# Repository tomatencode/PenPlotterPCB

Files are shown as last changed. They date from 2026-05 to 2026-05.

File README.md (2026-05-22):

# Pen Plotter Controller Board

Eine selbst entworfene PCB-Steuerplatine für einen DIY Pen Plotter, entwickelt in KiCad. Die Platine steuert zwei Schrittmotoren für die XY-Bewegung, einen Servo für den Stifthub und übernimmt Benutzerführung sowie Energiemanagement vollständig auf einer einzigen Platine.

## Funktionen

- **ESP32** – Haupt-Mikrocontroller (Breakout aufgelötet) für Bewegungssteuerung und Logik
- **2× TMC2209** – Schrittmotortreiber (Breakouts aufgelötet) mit UART-Konfiguration, stealthChop und stallGuard
- **SG90 Servo** – Stift-Auf/Ab-Mechanismus
- **I2C LCD-Display** – Angeschlossen über Steckverbinder
- **Drehgeber** – Manuelle Steuerung und Menünavigation über Steckverbinder
- **Buzzer** – Akustisches Feedback
- **Lüfter** – Transistorgesteuerter Lüfter zur Kühlung der Motortreiber
- **5V Buck Converter** – (Breakout aufgelötet) Erzeugt die interne 5V-Versorgungsschiene aus 24V
- **24V DC-Eingang** – Versorgung über externen Transformator (DC-Hohlbuchse)

## Stromversorgungsarchitektur

| Schiene | Quelle | Verbraucher |
|---|---|---|
| 24 V | Externer Transformator (DC-Buchse) | TMC2209 Motorspannung, Lüfter |
| 5 V | Buck Converter Breakout | ESP32, Servo, Buzzer, LCD |
| 3,3 V | Interner LDO des ESP32 | TMC2209 Logikspannung, Drehgeber |

## Platinenübersicht

### Schaltplan
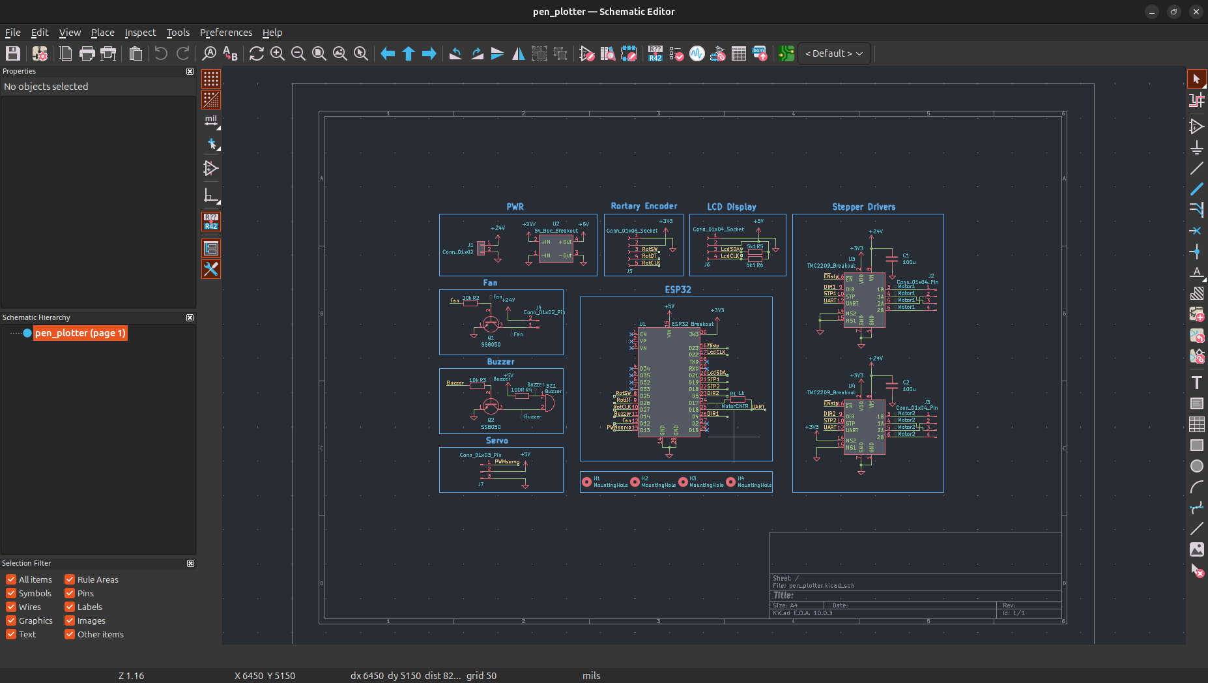
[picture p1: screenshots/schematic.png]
Schaltplan


### PCB-Layout
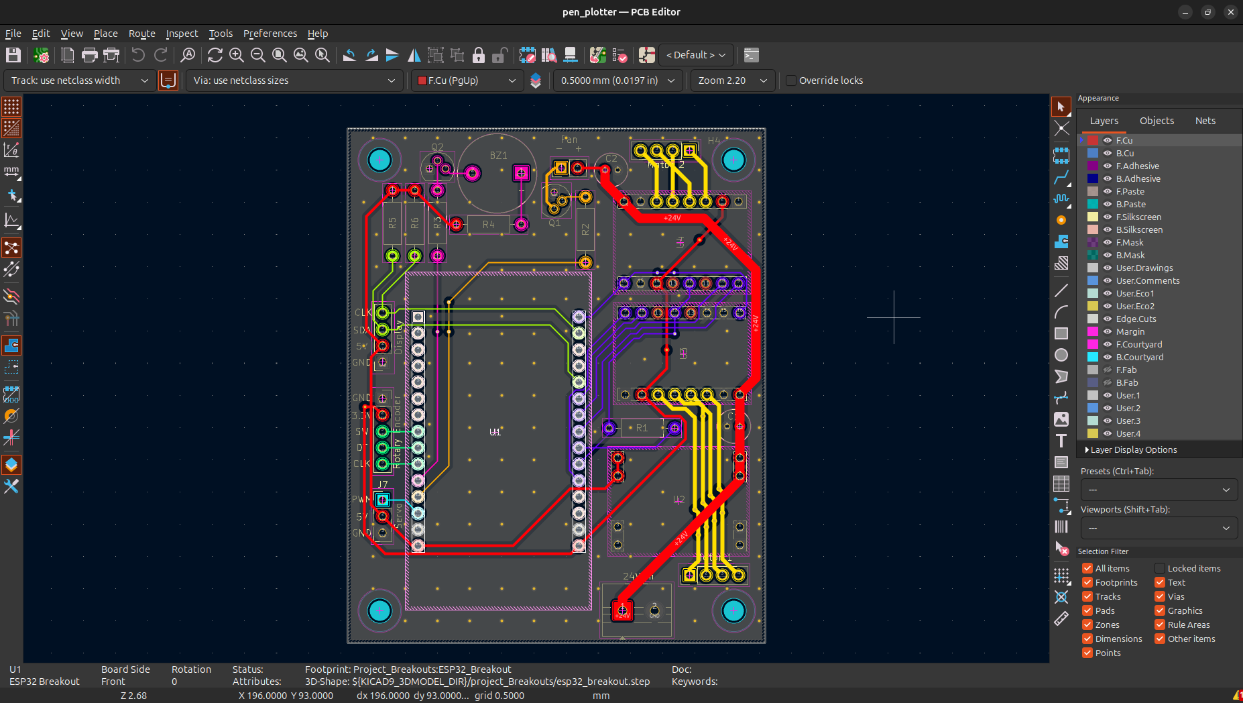
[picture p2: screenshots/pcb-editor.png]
PCB-Layout


### 3D-Ansicht
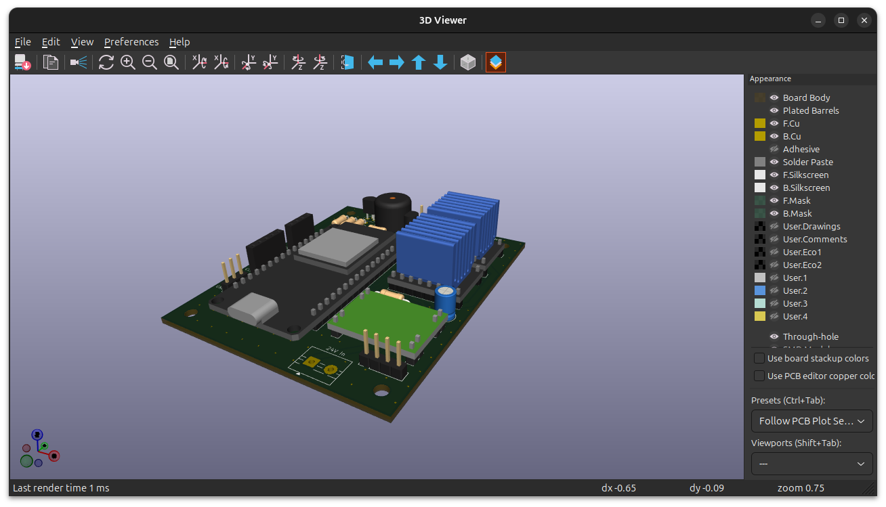
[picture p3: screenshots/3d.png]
3D-Ansicht


## Entwickelt mit

- [KiCad](https://www.kicad.org/) – Schaltplan und PCB-Layout

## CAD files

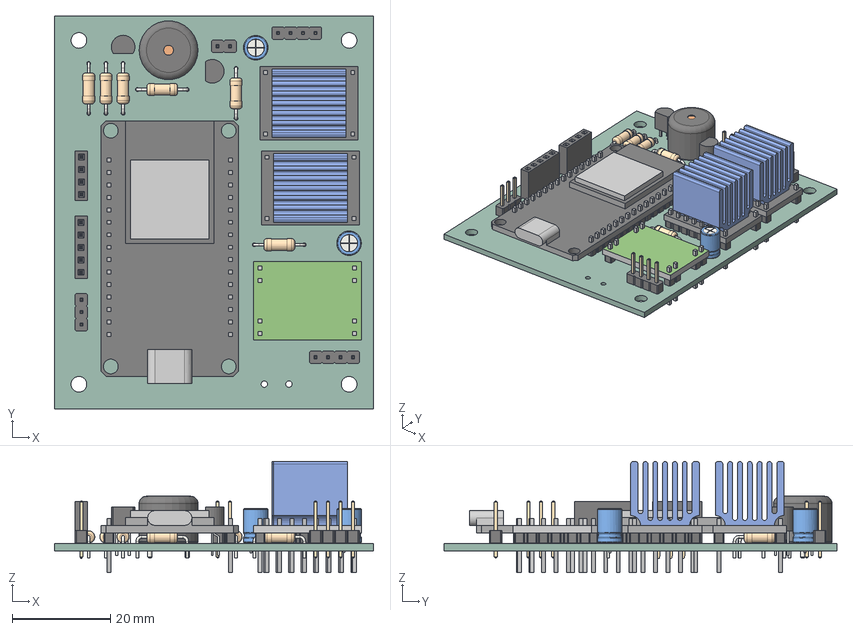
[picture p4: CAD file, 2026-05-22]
pen_plotter.step
65.0 x 80.0 x 22.6 mm
TO-92 x 2
5V_Buc_Breakout
C_Radial_D5.0mm_H7.0mm_P2.00mm x 2
PinHeader_1x03_P2.54mm_Vertical
R_Axial_DIN0207_L6.3mm_D2.5mm_P10.16mm_Horizontal x 6
PinHeader_1x04_P2.54mm_Vertical x 2
TMC2209_Breakout x 2
esp32_breakout
PinHeader_1x02_P2.54mm_Vertical
PinSocket_1x04_P2.54mm_Vertical
Buzzer_12x9.5RM7.6
PinSocket_1x05_P2.54mm_Vertical
pen_plotter_PCB

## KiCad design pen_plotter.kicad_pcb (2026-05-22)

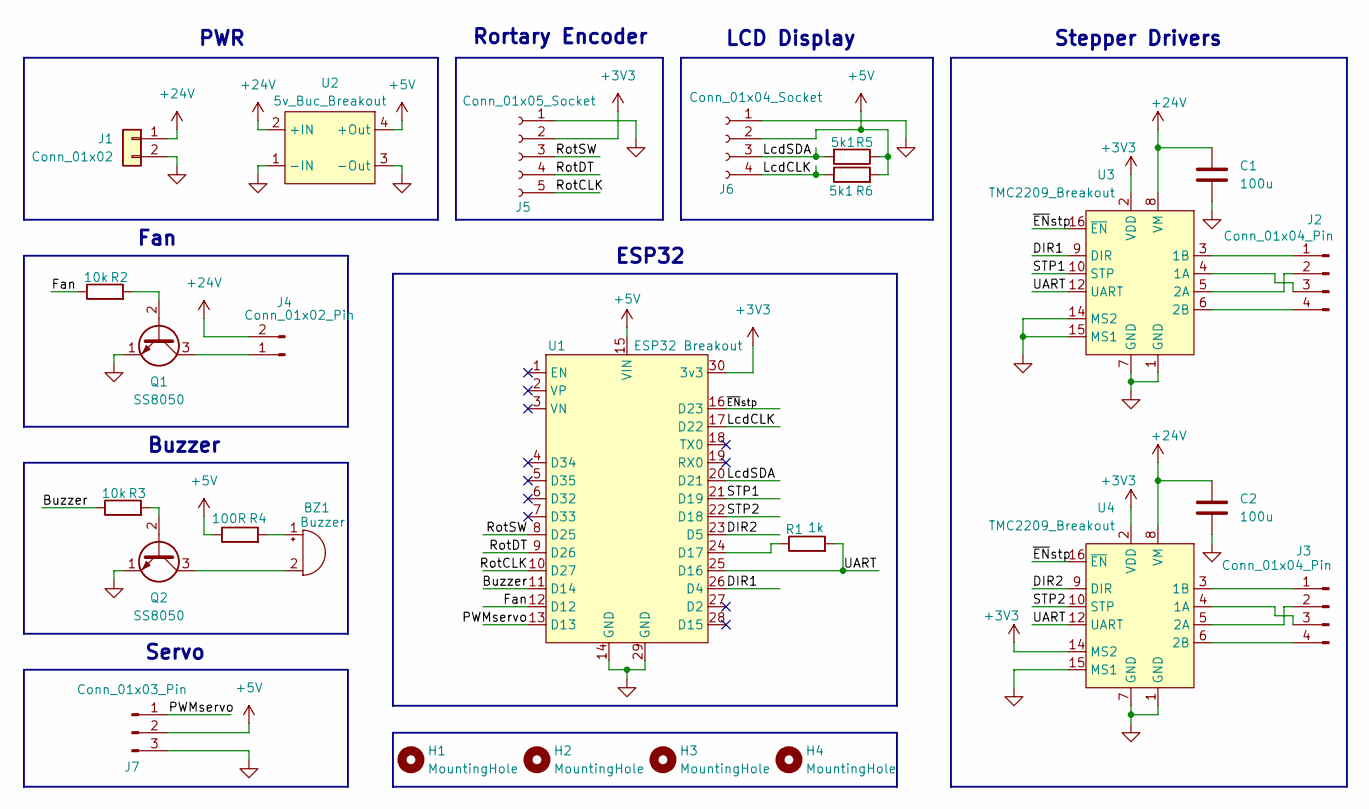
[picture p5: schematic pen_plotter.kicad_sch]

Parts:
BZ1: Buzzer; Buzzer_12x9.5RM7.6
C1, C2: 100u; C_Radial_D5.0mm_H7.0mm_P2.00mm
H1, H2, H3, H4: MountingHole; MountingHole_3.2mm_M3
J1: Conn_01x02; TerminalBlock_MaiXu_MX126-5.0-02P_1x02_P5.00mm
J2, J3: Conn_01x04_Pin; PinHeader_1x04_P2.54mm_Vertical
J4: Conn_01x02_Pin; PinHeader_1x02_P2.54mm_Vertical
J5: Conn_01x05_Socket; PinSocket_1x05_P2.54mm_Vertical
J6: Conn_01x04_Socket; PinSocket_1x04_P2.54mm_Vertical
J7: Conn_01x03_Pin; PinHeader_1x03_P2.54mm_Vertical
Q1, Q2: SS8050; TO-92
R1: 1k; R_Axial_DIN0207_L6.3mm_D2.5mm_P10.16mm_Horizontal
R2, R3: 10k; R_Axial_DIN0207_L6.3mm_D2.5mm_P10.16mm_Horizontal
R4: 100R; R_Axial_DIN0207_L6.3mm_D2.5mm_P10.16mm_Horizontal
R5, R6: 5k1; R_Axial_DIN0207_L6.3mm_D2.5mm_P10.16mm_Horizontal
U1: ESP32 Breakout; ESP32_Breakout
U2: 5v_Buc_Breakout; 5V_Buc_Breakout
U3, U4: TMC2209_Breakout

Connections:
+3V3: J5.2, U1.30 (3v3), U3.2 (VDD), U4.2 (VDD), U4.14 (MS2)
+5V: J6.2, J7.2, R4.1, R5.1, R6.2, U1.15 (VIN), U2.4 (+Out)
+24V: C1.1, C2.1, J1.1, J4.2, U2.2 (+IN), U3.8 (VM), U4.8 (VM)
/Buzzer: R3.1, U1.11 (D14)
/DIR1: U1.26 (D4), U3.9 (DIR)
/DIR2: U1.23 (D5), U4.9 (DIR)
/Fan: R2.1, U1.12 (D12)
/LcdCLK: J6.4, R6.1, U1.17 (D22)
/LcdSDA: J6.3, R5.2, U1.20 (D21)
/PWMservo: J7.1, U1.13 (D13)
/RotCLK: J5.5, U1.10 (D27)
/RotDT: J5.4, U1.9 (D26)
/RotSW: J5.3, U1.8 (D25)
/STP1: U1.21 (D19), U3.10 (STP)
/STP2: U1.22 (D18), U4.10 (STP)
/UART: R1.2, U1.25 (D16), U3.12 (UART), U4.12 (UART)
/~ENstp: U1.16 (D23), U3.16 (~EN), U4.16 (~EN)
GND: C1.2, C2.2, J1.2, J5.1, J6.1, J7.3, Q1.1 (E), Q2.1 (E), U1.14 (GND), U1.29 (GND), U2.1 (-IN), U2.3 (-Out), U3.1 (GND), U3.7 (GND), U3.14 (MS2), U3.15 (MS1), U4.1 (GND), U4.7 (GND), U4.15 (MS1)
unnamed: BZ1.1 (+), R4.2
unnamed: BZ1.2 (-), Q2.3 (C)
unnamed: J2.1, U3.3 (1B)
unnamed: J2.2, U3.5 (2A)
unnamed: J2.3, U3.4 (1A)
unnamed: J2.4, U3.6 (2B)
unnamed: J3.1, U4.3 (1B)
unnamed: J3.2, U4.5 (2A)
unnamed: J3.3, U4.4 (1A)
unnamed: J3.4, U4.6 (2B)
unnamed: J4.1, Q1.3 (C)
unnamed: Q1.2 (B), R2.2
unnamed: Q2.2 (B), R3.2
unnamed: R1.1, U1.24 (D17)

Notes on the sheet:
Stepper Drivers
Rortary Encoder
LCD Display
Buzzer
PWR
Servo
Fan
ESP32

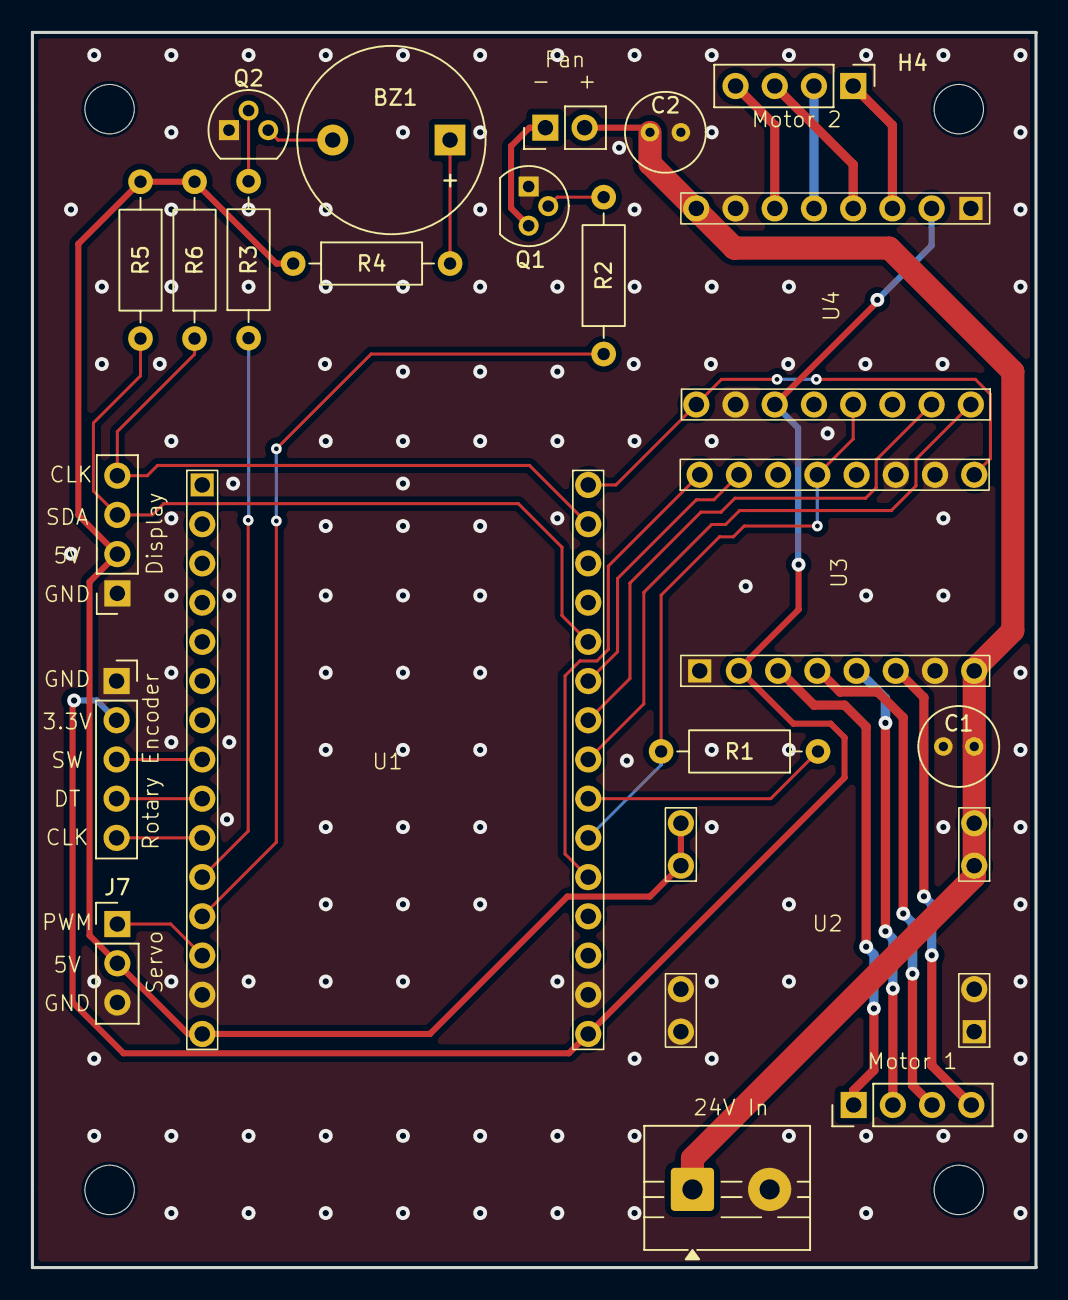
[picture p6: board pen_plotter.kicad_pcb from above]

Board: 2 copper layers, 65.0 x 80.0 mm, 26 parts (0 on the bottom side), 32 nets.
